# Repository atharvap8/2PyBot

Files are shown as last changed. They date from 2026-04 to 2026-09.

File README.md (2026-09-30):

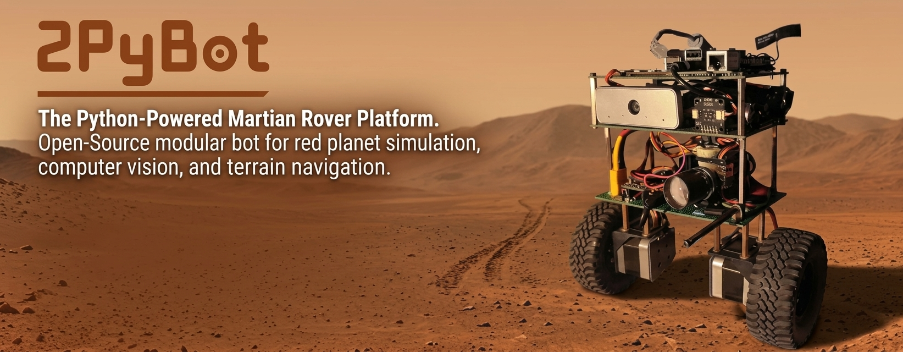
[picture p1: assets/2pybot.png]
2PyBot: The Python-Powered Martian Rover Platform


# 2PyBot: Self-Balancing Robot








2PyBot is an ESP32 self-balancing robot with NEMA 17 steppers, TMC2226 drivers, MT6816 wheel encoders, and an ISM6HG256X IMU. The firmware uses **LQR/LQI state feedback** for balance and position hold. An EVOFOX One S gamepad pairs directly through Bluepad32. USB serial carries host drive commands, telemetry, and parameter tuning.

## Current firmware

- 200 Hz control loop using pitch, pitch rate, wheel position, velocity, and position integral.
- 20 kHz timer ISR for STEP/DIR pulses; hardware PCNT for encoder counts.
- Encoder-differential heading hold and slew-limited steering.
- Normal hold, stiff hold, velocity tracking, and climb reference tracking.
- Terrain roughness, airborne, and landing detection with pitch-gain softening.
- 106 runtime parameters with per-value bounds and NVS save/load.
- Auto-tuning routines for wobble, trim, radius, and stall speed, with current limitations documented in the tuning guide.
- WS2812 status ring, camera pan/zoom servos, and PWM torch.

## Control and communication

The gamepad's left stick drives and steers. The right stick pans and zooms the camera. START requests arming; SELECT stops balancing. LB toggles LOW/HIGH speed, RB toggles the torch, and the D-pad controls hold modes and torch brightness.

Fresh host `V,<forward>,<steering>,<enable>` commands take priority over gamepad driving. `V` commands do not arm the robot. Use gamepad START or serial `E`. With no fresh input, drive commands become zero and balancing continues.

USB serial runs at **460800 baud**. The firmware emits `O` odometry at 50 Hz and `D` debug telemetry at a nominal 100 Hz. Debug starts enabled; `L` toggles it. See the [serial protocol](firmware/BaseLink/PROTOCOL.md) for fields and commands.

## Repository layout

```text
firmware/
  BaseLink/                 Robot firmware and serial protocol
    BaseLink.ino            State machine, control, input arbitration
    config.h                Pins and compiled defaults
    params.h / params.cpp   Runtime parameters and NVS persistence
    autotune.h              Calibration and tuning routines
    terrain.h               Roughness, airborne, and landing detection
    bt_gamepad.h            Bluepad32 input mapping
    imu_sensor.h / .cpp      Mahony attitude estimation
    stepper_control.h / .cpp TMC2226 configuration, PCNT, step ISR
    led_ring.h / .cpp        WS2812 status display
    payload.h               Camera servos and torch
  Controller/               Legacy ESP-NOW joystick transmitter
software/
  android/                  Kotlin/Compose Android app
  radxa/
    console/                Current browser console and Android API
    deployment/             Installed services, MediaMTX, and device rules
  runtime/vision_controller/ Older collision guard and person follower
gui/                        Legacy PID desktop interface
tools/
  controller_lab/           Browser simulation lab
  tuner/                    Legacy Web Serial PID tuner
docs/                       Architecture, control theory, tuning, history
scripts/                    Model generation and Radxa utilities
hardware/cad/enclosure/rev5/ OpenSCAD enclosure source and STL exports
models/                     CAD assets
assets/                     Project media
```

## Build and first connection

1. Install the ESP32 + Bluepad32 board package and the libraries listed in the [firmware setup guide](firmware/BaseLink/README.md).
2. Select ESP32 Dev Module with the Huge APP partition scheme.
3. Open `firmware/BaseLink/BaseLink.ino`, review the pin assignments in `config.h`, and flash.
4. Open USB serial at 460800 baud with newline termination. Check the IMU and driver boot messages, then send `P?` to inspect loaded parameters.
5. Pair the EVOFOX One S in Home+B mode. Leave both sticks centered while calibration completes.
6. Verify motor and sensor signs using the [configuration guide](docs/BaseLink/Config_and_Tuning_Guide.md), then request arming while upright.

Saved NVS parameters take precedence over compiled defaults. `PD` restores defaults in RAM; `PS` saves them.

## Host software status

| Component | Current compatibility |
| :--- | :--- |
| USB terminal or custom serial client | Supports the current parameter and telemetry protocol |
| `software/radxa/console/` | Current Radxa console: 460800 baud, live parameter metadata, browser UI, Android API, and WebRTC camera |
| `software/android/` | Kotlin/Compose client for console HTTP/WebSocket and MediaMTX WHEP; parameter groups are dynamic |
| `software/runtime/vision_controller/radxa_brain.py` | Uses `O` and `V` messages, but still has 115200 baud and 0.035 m radius constants; align both before use |
| `gui/robot_controller_ui.py` | Legacy PID UI: 115200 baud, tab-separated telemetry, and `$` commands; needs a protocol update |
| `tools/tuner/tuner.html` | Legacy Web Serial PID tuner; not a current parameter-store client |
| `firmware/Controller/Controller.ino` | Legacy ESP-NOW transmitter; current BaseLink has no ESP-NOW receiver |

The current console package was imported from the Cubie A7A. See its [setup and API guide](software/radxa/console/README.md) and [deployment layout](software/radxa/README.md). Its debug parser reads the original 15 fields; terrain telemetry and a terrain parameter tab remain pending.

The older Radxa brain provides GUARD/FOLLOW modes. It owns the camera and serial port, so it cannot run alongside the console. See its [setup guide](software/runtime/vision_controller/README_RADXA.md).

The [Android app](software/android/README.md) has Live, Map, Tune, Auto, Camera, and Setup screens. It defaults to the Radxa hotspot address `10.42.0.1`. Its Tune screen includes all groups reported by firmware, including TERRAIN. APK build instructions and CI artifacts are documented with the app.

## Updating the bot

The console runs from `/home/radxa/projects/2PyBot`. After `git pull --ff-only`, a systemd timer applies relevant committed changes and restarts the affected services. Android, CAD, firmware, and documentation changes do not restart the console. See [repo-based deployment](scripts/radxa/README.md) for installation, status, and retry commands.

## Hardware defaults

| Component | Configuration |
| :--- | :--- |
| Robot controller | ESP32 DevKit |
| Wheel drive | Two NEMA 17 motors, TMC2226 drivers, 1/8 microsteps |
| Wheel feedback | MT6816 quadrature encoders, 4096 counts/revolution |
| Wheel radius | 0.050 m compiled default |
| Attitude | ISM6HG256X accelerometer/gyro, Mahony filter |
| Compass | QMC5883L, tilt-compensated yaw telemetry |
| Gamepad | EVOFOX One S through Bluepad32 |
| Status ring | 16 WS2812 LEDs on GPIO 15 |
| Camera payload | MG90S pan/zoom servos on GPIO 26/0; torch on GPIO 2 |

## Enclosure CAD

[Revision 5](hardware/cad/enclosure/rev5/README.md) includes the base tray, shell, face plate, and left/right motor covers as OpenSCAD source and five STL exports. The enclosure is **not yet printed or physically fit-tested**. Estimated dimensions are marked in the source. The imported face STL has three zero-area triangles that need re-export or repair before printing.

The existing simplified STEP model remains in `models/2pybot_simplified.step`; it is separate from the revision-5 enclosure package.

## Documentation

| Document | Contents |
| :--- | :--- |
| [Firmware setup](firmware/BaseLink/README.md) | Build, wiring, pairing, controls |
| [Serial protocol](firmware/BaseLink/PROTOCOL.md) | Commands, parameter records, telemetry fields |
| [Radxa console](software/radxa/console/README.md) | Browser UI, Android API, camera pipeline, deployment |
| [Android app](software/android/README.md) | Build, host connection, screens, parameter and video transport |
| [Radxa deployment](scripts/radxa/README.md) | Git updates, selective restarts, systemd timer, health checks |
| [Enclosure CAD](hardware/cad/enclosure/rev5/README.md) | Revision-5 source, exports, dimensions, and current print status |
| [System architecture](docs/BaseLink/System_Architecture.md) | Sensors, control, actuation, host links |
| [LQR/LQI theory](docs/BaseLink/PID_Theory_and_Math.md) | State feedback, control modes, filtering, limits |
| [Configuration and tuning](docs/BaseLink/Config_and_Tuning_Guide.md) | Defaults, runtime settings, calibration |
| [Program flow](docs/BaseLink/Program_Flow_State_Machine.md) | Boot sequence and state transitions |
| [Troubleshooting](docs/BaseLink/Troubleshooting_Guide.md) | Common faults and source-level checks |
| [Detailed reference](docs/BaseLink/100+_WHAT_AND_HOWS.md) | 126 code-mapped checks |
| [TMC2226 migration](docs/BaseLink/TMC2226_Migration.md) | Driver configuration and migration history |
| [Project history](docs/BaseLink/Project_History.md) | PID, ESP-NOW, LQR/LQI, and runtime-tuning milestones |
| [Legacy transmitter](docs/Controller/System_Architecture.md) | ESP-NOW joystick packet and sampling |

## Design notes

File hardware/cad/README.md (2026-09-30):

# Robot CAD

## Packages

| Path | Contents | Status |
| :--- | :--- | :--- |
| [enclosure/rev5/](enclosure/rev5/README.md) | Parametric OpenSCAD enclosure and five STL exports | Designed; not printed or physically fit-tested |
| [Existing STEP model](../../models/2pybot_simplified.step) | Simplified robot model | Separate reference model |

Revision 5 keeps its SCAD sources, logo SVG, and STL exports together to preserve relative references. Shared dimensions are in `dims.scad`, with part-specific dimensions in the individual sources.

The face STL has three zero-area triangles. Other imported STL edge checks passed. Assembly clearances and printer tolerances still need validation on the physical parts.

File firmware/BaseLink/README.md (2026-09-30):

# BaseLink Firmware

ESP32 robot firmware with LQR/LQI balancing, direct Bluepad32 gamepad input, runtime parameters, terrain adaptation, a WS2812 ring, and camera payload control.

## Build

Open `BaseLink.ino` from this folder. The sketch filename must match the `BaseLink` directory name.

Add both board-manager URLs in Arduino IDE preferences:

```text
https://raw.githubusercontent.com/espressif/arduino-esp32/gh-pages/package_esp32_index.json
https://raw.githubusercontent.com/ricardoquesada/esp32-arduino-lib-builder/master/bluepad32_files/package_esp32_bluepad32_index.json
```

Install **ESP32 + Bluepad32 Arduino**, select **ESP32 Dev Module**, and choose **Huge APP (3 MB)**. Firmware CI uses `esp32-bluepad32:esp32@4.1.0` with this FQBN:

```text
esp32-bluepad32:esp32:esp32:PartitionScheme=huge_app
```

Install these libraries:

- TMCStepper
- STM32duino ISM6HG256X
- QMC5883LCompass
- NeoPixelBus by Makuna

`Preferences` comes with the ESP32 core. The stock ESP32 board package does not supply `Bluepad32.h`. The separate legacy Controller sketch uses the stock ESP32 3.x core.

## Pin map

Values below come from `config.h`.

| Signal | GPIO |
| :--- | :--- |
| Right STEP / DIR | 33 / 25 |
| Left STEP / DIR | 27 / 14 |
| Shared motor EN | 32, active LOW |
| Right UART RX / TX | 16 / 17 |
| Left UART RX / TX | 18 / 19 |
| I2C SDA / SCL | 21 / 22 |
| Left encoder A / B | 4 / 5 |
| Right encoder A / B | 13 / 23 |
| Optional left / right DIAG | 34 / 35 |
| WS2812 DIN | 15 |
| Camera pan / zoom | 26 / 0 |
| Torch MOSFET gate | 2 |

Each driver has a separate UART with a 1 kOhm series resistor on TX. Both drivers use address 0 with MS1/MS2 LOW. Both enable inputs share GPIO 32.

Power the ring and servos from the 5 V rail with common ground. The ring has 16 LEDs, a compiled brightness setting of 200/255, and a 50 Hz refresh setting. GPIO 0 and GPIO 2 are boot-strapping pins; external wiring must preserve their required reset levels.

## Boot and serial connection

Use USB serial at **460800 baud**, 8N1, with newline termination.

Boot loads NVS parameters, plays the ring animation, initializes sensors and drivers, waits 3000 ms, averages 500 gyro readings, then starts the gamepad and payload. The balance state starts at `STATE_IDLE`.

Check for:

```text
[PARAM] 106 tunables ...
[IMU] Initialisation OK
[STEP] RIGHT TMC2226: OK ... readback 1/8 ...
[STEP] LEFT TMC2226: OK ... readback 1/8 ...
[PAD] Bluepad32 ready ...
```

Driver communication errors print per-driver `COMM ERROR` messages. They do not halt setup. IMU initialization failure does halt setup.

Send `P?` to inspect the live settings. `PL` reloads NVS and applies driver tuning after initialization. `PD` restores defaults in RAM; `PS` persists the current settings.

## Gamepad pairing

Put the EVOFOX One S in **Home+B** pairing mode. Keep both sticks centered until the center-calibration log appears. Firmware adopts held buttons on the first processed connection frame; release START before pressing it to arm.

If pairing keys need clearing, enable the existing `BP32.forgetBluetoothKeys()` call for one flash, pair again, then disable that call.

## Controls

| Input | Action |
| :--- | :--- |
| Left stick Y | Forward/backward drive |
| Left stick X | Steering |
| Right stick X | Camera pan rate |
| Right stick Y | Camera zoom rate |
| START | Request arming |
| SELECT | Stop balancing |
| LB | Toggle LOW/HIGH speed |
| RB | Toggle torch |
| D-pad UP | Toggle stiff hold |
| D-pad DOWN | Toggle climb mode |
| D-pad LEFT / RIGHT | Dim / brighten torch; repeat while held |
| Y / B / X / A | Nod yes / nod no / spin / dance |

LOW mode defaults to half drive and steering authority. Boot defaults to LOW. Speed mode remains selected across arm/disarm and reconnection.

`PAD_STEER_ON_LEFT_STICK=0` moves steering to right-stick X and disables camera pan input. This is a compile-time mapping choice.

## Balance and host control

Use START or serial `E` while the robot is within the arm-angle limit, default 5 degrees. `X` or SELECT stops balancing. Tilt beyond 55 degrees or pitch rate beyond 450 degrees/s also stops balancing.

Fresh host `V` lines override gamepad drive for 600 ms by default. Host enable going from 1 to 0 requests a stop; going to 1 does not arm. A first `V,...,0` is not an unconditional stop, so use `X` for an explicit balancing stop.

Gamepad disconnect zeros its axes without disabling balance. When all drive sources are stale, the controller receives zero drive input.

## Ring states

Priority order in `leds_update()`:

1. Fall, arm, or speed-change overlay.
2. Gesture rainbow.
3. Red hazard when host input is fresh, the robot is balancing, drive input is near zero, and measured speed exceeds 0.10 m/s.
4. Violet climb display.
5. Pink position-error display above 0.045 m while holding.
6. Direction beam while driving; amber for reverse.
7. Amber stiff-hold display.
8. Cyan balancing display with tilt-dependent color.
9. Green pending-arm display.
10. Idle ember display.

The hazard display is conditional, not a general indicator that the host owns drive authority. A green gamepad greeting is blended into selected patterns.

## Payload

Pan and zoom use LEDC channels 4/5 at 50 Hz and 16-bit resolution. Torch uses channel 6 at 20 kHz and 10-bit resolution. Camera input is rate-controlled, so releasing the stick leaves the requested position unchanged.

Pan defaults to 120 through 190 degrees with home 165; zoom defaults to 80 through 140 with home 120. The pulse-writing function clamps physical output to 180 degrees even when the requested pan value is higher.

Torch starts off with a compiled preset of 25%. `_torchApply()` clamps duty to the 90% compile-time cap. Payload updates run in both balance states. No disarm-time torch-off call is present in the current sketch.

## Related documentation

- [Serial protocol](PROTOCOL.md)
- [Module map](system_architecture.md)
- [Control theory](../../docs/BaseLink/PID_Theory_and_Math.md)
- [Configuration and tuning](../../docs/BaseLink/Config_and_Tuning_Guide.md)
- [Troubleshooting](../../docs/BaseLink/Troubleshooting_Guide.md)

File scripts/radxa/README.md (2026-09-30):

# Repo-Based Radxa Deployment

The bot runs the console from a Git checkout at `/home/radxa/projects/2PyBot`. A systemd timer checks the local commit about every ten seconds. It does not fetch or pull from GitHub.

## Update

```bash
cd /home/radxa/projects/2PyBot
git pull --ff-only
```

The deployment service waits for Git to finish and rejects tracked local edits. Build/dependency checks happen before service changes. A second Git update during preparation defers deployment to the next check.

## What causes a restart

| Change | Action |
| :--- | :--- |
| Console Python or browser JS/HTML/CSS | Check Python imports, restart console |
| `requirements.txt` | Update the dedicated environment, check imports, restart console |
| Native C/header/Makefile | Build the encoder, restart console |
| Console service template or camera override | Install changed file, reload systemd, restart console |
| MediaMTX source configuration or service | Install changed file, restart MediaMTX and console |
| Encoder device rules | Install/reload rules, restart console |
| Deployment timer/service templates | Update the monitor units |
| Firmware, Android, CAD, documentation | Record the commit without restarting handlers |

The live configuration is `software/radxa/console/mediamtx.yml`. Files under `software/radxa/deployment/` are captured deployment references, not active update inputs.

Firmware still needs a separate compile/flash step. An Android source update needs a separate APK build/install.

## Initial installation

The board needs Git, Python 3.9 or newer with venv/pip, make, the existing console dependencies, MediaMTX, and the Cedar SDK/development libraries described in [the native guide](../../software/radxa/console/native/README.md).

```bash
cd /home/radxa/projects/2PyBot
sudo python3 scripts/radxa/deploy.py --user radxa --force --install-monitor
```

This uses the console service templates with the checkout path and a dedicated Python environment. It does not run the hotspot installer or change NetworkManager configuration.

## Runtime paths

| Path | Contents |
| :--- | :--- |
| `/var/lib/2pybot/` | Existing user camera profiles |
| `/var/lib/2pybot-deploy/venv/` | Dedicated Python environment using available system/user packages |
| `/var/lib/2pybot-deploy/state.json` | Last successfully applied commit and actions |
| `/var/lib/2pybot-deploy/backups/` | Previous installed configuration files, grouped by target commit |
| `/run/2pybot-deploy.lock` | Lock preventing overlapping deployments |
| `/etc/2pybot/mediamtx.yml` | Installed streaming configuration |

State is updated only after commands and service health checks succeed. If video was running before a relevant update, its recovery is also checked. ESP32 serial connection is not required for deployment health.

The monitor runs installation commands as root but reads Git as the checkout owner. This supports the board's Git 2.30 without global ownership exceptions. The console service disables bytecode writes in the source checkout.

## Inspect or retry

```bash
systemctl status 2pybot-deploy.timer
journalctl -u 2pybot-deploy.service -n 50
cat /var/lib/2pybot-deploy/state.json
sudo systemctl start 2pybot-deploy.service
```

Preview pending actions without applying them:

```bash
python3 scripts/radxa/deploy.py --dry-run
```

If a deployment fails, the previous marker stays in place and the timer retries. The script does not reset the checkout or automatically roll back application code. Configuration backups are retained for manual recovery.

`pair2.sh` is the older Linux gamepad-pairing helper. Current BaseLink pairs its gamepad directly to the ESP32.

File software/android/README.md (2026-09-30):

# 2PyBot Android App

Native Kotlin and Jetpack Compose client for the [Radxa console](../radxa/console/README.md). The app uses HTTP for commands and settings, WebSocket for telemetry, and WebRTC/WHEP for camera video.

## Build configuration

| Setting | Value |
| :--- | :--- |
| Application ID / namespace | `in.twopybot.app` |
| Minimum Android version | API 26, Android 8.0 |
| Compile / target SDK | API 34 |
| Java target | 17 |
| Gradle wrapper | 8.9 |
| Android Gradle plugin | 8.5.2 |
| Kotlin | 1.9.24 |
| Compose compiler | 1.5.14 |
| Default robot host | `10.42.0.1` |

Open this directory in Android Studio with JDK 17 and Android SDK 34 installed. The Gradle wrapper scripts, properties, and JAR are included.

The imported Windows wrapper's two missing-Java branches were corrected to return immediately instead of falling through into Gradle startup.

From Windows:

```powershell
.\gradlew.bat :app:assembleDebug
```

From Linux or macOS:

```bash
bash gradlew :app:assembleDebug
```

Debug APK: `app/build/outputs/apk/debug/app-debug.apk`.

`assembleRelease` produces an unsigned release APK. No signing key is included. Machine-specific SDK paths belong in ignored `local.properties`, or use `ANDROID_HOME`.

## Build helper and CI

`build.sh` supports debug, run, release, clean, setup, and doctor modes. Its setup commands use Arch Linux `pacman`; they are not a generic Linux installer.

```bash
bash build.sh doctor
bash build.sh
bash build.sh run
```

The repository's [Android workflow](../../.github/workflows/android.yml) builds debug and unsigned release APKs when Android files change on `main` or `system/**`, on matching pull requests, or through manual dispatch. Artifacts are `2pybot-apk` and `2pybot-apk-release-unsigned`.

## Connection

Join the Radxa hotspot or use its LAN address. Enter the host address in Setup. The app connects to:

| Interface | Address |
| :--- | :--- |
| HTTP API | `http://<host>:8080` |
| Telemetry WebSocket | `ws://<host>:8080/ws` |
| Video | `http://<host>:8889` plus the WHEP path reported by the console |

Default WHEP path is `/cam/whep`. The current Android network configuration permits cleartext traffic through its base configuration; it is not restricted to private IP ranges.

The app communicates with the Radxa, not directly with the ESP32. The console owns USB serial and relays firmware records and parameter writes.

## Screens

| Screen | Contents |
| :--- | :--- |
| Live | WHEP camera, attitude gauge, controller debug values, gesture controls |
| Map | Console dead-reckoned trail and pose; local pose reset |
| Tune | Parameter groups, values, bounds, descriptions, Save/Reload/Defaults |
| Auto | Wobble, trim, radius, and stall commands with progress logs |
| Camera | V4L2 settings, named profiles, exposure/gain adjustment, stream settings |
| Setup | Robot address, stream status, stop control, console logs |

Portrait uses a bottom navigation bar and top stop button. Landscape uses a navigation rail with stop control and wider two-pane screens. See [landscape and auto-tuning](LANDSCAPE_AND_AUTOTUNE.md).

## Parameters and commands

Tune builds its group list from the console parameter payload. Current firmware has **106 parameters in ten groups**, including TERRAIN. Unlike the browser's fixed tab list, the Android group list includes new groups automatically.

Parameter writes change firmware RAM. Save sends the NVS save action; Reload loads saved values; Defaults restores compiled settings without saving.

The console whitelist excludes `E` and `V`, so this app has no direct joystick-driving or balance-arm command. It can send gestures, hold-mode commands, and auto-tune routines. The displayed pad values come from controller debug after input arbitration, and the connection indicator is not a Bluetooth-gamepad pairing status.

The stop button calls `/api/estop`, which sends firmware `X`. That command stops balancing but does not abort the current firmware's stall-search routine. Use Auto's Abort action for `AT,stop`. Radius Done currently encounters the firmware busy-guard bug.

## Source map

| File | Responsibility |
| :--- | :--- |
| `MainActivity.kt` | Six destinations, portrait/landscape navigation, stop control |
| `data/BotRepository.kt` | HTTP/WebSocket models, parameter requests, progress logs, WHEP URL |
| `vm/BotViewModel.kt` | Saved host setting and UI command actions |
| `net/WhepClient.kt` | Receive-only video track, SDP exchange, decoder factory |
| `ui/screens/` | Live, Map, Tune, Auto, Camera, Setup |
| `ui/Responsive.kt` | Orientation helpers |
| `ui/components/Widgets.kt` | Reusable gauges, parameter rows, and status components |

Kotlin files are under `app/src/main/java/in/twopybot/app/`.

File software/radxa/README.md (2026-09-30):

# Radxa Software

The current browser console and Android API are in [console/](console/README.md). The package was imported from `/home/radxa/2pybot-console` on the Cubie A7A.

## Layout

| Path | Contents |
| :--- | :--- |
| `console/console/` | FastAPI server, USB protocol client, camera control, stream supervisor |
| `console/ui/` | Browser interface and parameter tabs |
| `console/native/` | Cedar H.264 publisher source, build file, encoder device rules |
| `console/systemd/` | Installer service templates |
| `deployment/systemd/` | Installed service definitions and camera startup override captured from the board |
| `deployment/udev/` | Installed serial and encoder device rules |
| `deployment/mediamtx.yml` | Live MediaMTX configuration captured from `/etc/2pybot` |
| `deployment/bin/` | Local copy of the installed MediaMTX binary; ignored by Git |
| `deployment/runtime/` | Local copy of saved camera profiles; ignored by Git |

The running board used MediaMTX **v1.9.3**. The console uses **460800 baud**, requests firmware parameter metadata, and serves HTTP/WebSocket on port **8080**. MediaMTX exposes WHEP on **8889**, RTSP on **8554**, and its local administration API on **9997**.

The [Android app](../android/README.md) consumes the console API and MediaMTX WHEP stream. It builds parameter groups dynamically from the firmware metadata.

The bot runs this package from `/home/radxa/projects/2PyBot/software/radxa/console`. A [commit-aware deployment timer](../../scripts/radxa/README.md) applies relevant changes after a manual `git pull --ff-only`.

The existing [vision controller](../runtime/vision_controller/README_RADXA.md) is a separate older host application. It must not open the same camera or serial port while the console is using them.

## Import record

The original source, backup files, executables, and deployed settings were downloaded to a local snapshot before importing. Application source and deployment configuration are kept here. Generated executables, captures, and device-specific runtime profiles are retained locally and excluded from commits.

The separate camera/ToF calibration application is outside this package. The camera controls already built into the console remain included.

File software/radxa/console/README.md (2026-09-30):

# 2PyBot Console

Browser tuning interface, telemetry, camera controls, and HTTP/WebSocket API for the Android app. Imported from the running Cubie A7A package at `/home/radxa/2pybot-console`.

The Kotlin/Compose client is in [software/android](../../android/README.md).

## Components

| Path | Responsibility |
| :--- | :--- |
| `console/server.py` | FastAPI endpoints, WebSocket feed, static browser UI |
| `console/serial_link.py` | Exclusive USB connection, parameter commands, telemetry parsing, dead reckoning |
| `console/config.py` | Serial, HTTP, camera, snapshot, and profile settings |
| `console/camera.py` | V4L2 controls, exposure/gain adjustment, profiles, JPEG snapshots |
| `console/stream.py` | Camera mode selection, encoder startup, progress metrics, process supervision |
| `ui/` | Browser shell, shared parameter renderer, twelve tabs |
| `native/` | Allwinner Cedar H.264 publisher and probe source |
| `systemd/` | Installer templates for console and MediaMTX |

## Firmware connection

Serial defaults to `/dev/ttyUSB0` at **460800 baud** with DTR/RTS disabled and exclusive ownership. The reader requests `P?` after connecting and retries when the port is unavailable.

- `P` rows populate the parameter editor, including bounds, group, and description.
- `PR` rows provide live geometry conversions; odometry uses `COUNTSM` when available, otherwise a 0.050 m radius fallback.
- `P!` acknowledges a write and requests a new dump.
- `PS`, `PL`, and `PD` provide firmware persistence actions.
- `O` records update pose and telemetry.
- `D` records populate the original 15 debug fields. The five newer terrain fields are currently ignored.

The browser has parameter tabs for BALANCE, STEPPER, DRIVE, YAW, SAFETY, IMU, CLIMB, LED, and PAYLOAD. Firmware TERRAIN parameters are available through the API, but a terrain tab is not registered yet. Map dead reckoning uses the fixed 0.155 m track width from `config.py`.

The API command whitelist excludes `E` and `V`. The gamepad remains connected to the ESP32. `AT,` commands are allowed, so the firmware's current stall-tuning limitations still apply.

## Addresses

| Interface | Address |
| :--- | :--- |
| Browser console and API | `http://<radxa-ip>:8080` |
| WebSocket telemetry | `ws://<radxa-ip>:8080/ws` |
| WebRTC WHEP | `http://<radxa-ip>:8889/cam/whep` |
| Local camera publication | `rtsp://127.0.0.1:8554/cam` |
| MediaMTX administration | `http://127.0.0.1:9997` |

The installed hotspot normally uses `10.42.0.1`. Use your configured hotspot password; no device credentials are stored in this package.

## Install on the Radxa

The current bot uses the repository checkout at `/home/radxa/projects/2PyBot`, with this application under `software/radxa/console`. Use [repo-based deployment](../../../scripts/radxa/README.md) for normal updates and service monitoring.

The standalone installer below is for dependency/hotspot setup on a new board. It is not needed for routine Git updates. Its service templates substitute the application's installation directory.

The installer needs root access and a hotspot password in `PSK`:

```bash
cd /home/radxa/2pybot-console
read -rs -p 'Hotspot password: ' PSK
export PSK
sudo -E bash install.sh
```

It installs Python/stream dependencies, creates `/var/lib/2pybot`, sets dialout/video membership, installs the serial udev rule, configures a NetworkManager hotspot, and installs the two services. MediaMTX is downloaded if not already installed; the captured board version was **v1.9.3**.

The native Cedar publisher is built separately. See [native/README.md](native/README.md) for SDK and development-package requirements. The source `install.sh` does not build that executable or install its encoder rules.

The running board also has a camera startup override. Install the captured override and encoder rule when restoring that setup:

```bash
sudo mkdir -p /etc/systemd/system/2pybot-console.service.d
sudo cp 20-camera-natural.conf /etc/systemd/system/2pybot-console.service.d/
sudo cp native/99-2pybot-encoder.rules /etc/udev/rules.d/
sudo udevadm control --reload-rules
sudo systemctl daemon-reload
sudo systemctl restart 2pybot-console
```

The deployed service definitions and live MediaMTX settings are also preserved in [deployment/](../deployment/). Those service definitions contain the original `/home/radxa/2pybot-console` path; the installer templates substitute the actual destination.

## Camera pipeline

For MJPEG modes, the console selects `native/2pybot_hwstream` when present. It decodes JPEG on the CPU, converts pixels, encodes H.264 with Cedar, publishes RTSP, and writes original JPEG snapshots to `/dev/shm/2pybot_snap.jpg`.

Without that executable, it probes FFmpeg hardware encoders and falls back to low-latency libx264. The supervisor restarts failed stream processes. `/api/stream` reports the selected mode, encoder, errors, and progress metrics.

Camera profiles are daylight, indoor, low_light, night, and driving. Built-in exposure adjustments cap absolute exposure at 300 units. User profiles live in `/var/lib/2pybot/camera_profiles.json`; the board's saved copy was downloaded as local runtime data.

## API

| Method and path | Purpose |
| :--- | :--- |
| `GET /api/status` | Connection, telemetry, debug, derived values, stream state, parameter count |
| `GET /api/params` | Parameters, groups, bounds, and dump status |
| `POST /api/params/set` | Send `{key, value}` |
| `POST /api/params/{save,load,defaults,refresh}` | Firmware parameter actions |
| `POST /api/command` | Send a whitelisted `{line}` |
| `POST /api/estop` | Send firmware `X` |
| `GET /api/path`, `POST /api/pose/reset` | Pose trail and local pose reset |
| `GET /api/log` | Recent console logs |
| `GET /api/camera/controls` | V4L2 controls, values, profiles, and camera modes |
| `POST /api/camera/set` | Set `{name, value}` |
| `POST /api/camera/profile/{name}` | Apply a camera profile |
| `POST /api/camera/autocalibrate` | Adjust exposure/gain from snapshot brightness |
| `GET /api/camera/snapshot`, `GET /api/camera/luma` | JPEG and brightness measurement |
| `GET /api/stream` | Stream state and metrics |
| `POST /api/stream/restart`, `POST /api/stream/stop` | Stream process control |
| `WS /ws` | 10 Hz telemetry, parameter acknowledgements, and logs |

`/api/camera/profile/save` is defined after the generic profile route in the imported code. Route ordering needs review before relying on profile saving through HTTP.

## Operation

```bash
systemctl status 2pybot-console 2pybot-mediamtx
journalctl -u 2pybot-console -f
journalctl -u 2pybot-mediamtx -f
```

Run only one application against the ESP32 serial port and camera. The older `radxa_brain.py` owns both and should not run alongside this console.

The separate camera/ToF calibration service was not imported. Camera controls contained in this console are part of the downloaded application.

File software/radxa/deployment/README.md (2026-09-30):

# Captured Cubie Deployment

Configuration downloaded from the running `2pybot` board with the console source. The original application path is `/home/radxa/2pybot-console` and the service user is `radxa`.

| Repository file | Original board path |
| :--- | :--- |
| `systemd/2pybot-console.service` | `/etc/systemd/system/2pybot-console.service` |
| `systemd/2pybot-console.service.d/20-camera-natural.conf` | `/etc/systemd/system/2pybot-console.service.d/20-camera-natural.conf` |
| `systemd/2pybot-mediamtx.service` | `/etc/systemd/system/2pybot-mediamtx.service` |
| `mediamtx.yml` | `/etc/2pybot/mediamtx.yml` |
| `udev/99-2pybot.rules` | `/etc/udev/rules.d/99-2pybot.rules` |
| `udev/99-2pybot-encoder.rules` | `/etc/udev/rules.d/99-2pybot-encoder.rules` |

These are the installed files, separate from the installer's templates. The camera drop-in is part of the deployed setup and applies natural-color controls before the console starts.

These captures describe the pre-Git standalone deployment. The current console service is rendered from its template for `/home/radxa/projects/2PyBot/software/radxa/console` by [the deployment script](../../../scripts/radxa/README.md). Edits to this captured directory do not trigger handler restarts.

MediaMTX was **v1.9.3**, running from `/usr/local/bin/mediamtx`. Its downloaded executable is retained locally at `bin/mediamtx`, which is ignored by Git. Saved camera profiles from `/var/lib/2pybot` are retained locally under `runtime/`, also ignored.

The live MediaMTX settings enable TCP RTSP on 8554, WebRTC on 8889 with UDP media on 8189, and the administration API on localhost 9997. The `cam` path accepts a publisher. HLS, RTMP, and SRT are disabled.

Use [the console setup guide](../console/README.md) when installing or restoring the application. Review the absolute paths before applying these captured service definitions to another board.

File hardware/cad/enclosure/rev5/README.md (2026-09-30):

# Enclosure Revision 5

OpenSCAD source and STL exports imported from `2pybot-covers-rev5`.

**Status: designed, not yet printed or physically fit-tested.** Dimensions marked `ROUGH` still need measurement against the assembled robot. Mesh checks do not establish physical clearance or printability.

## Files

| Source | Export | Part |
| :--- | :--- | :--- |
| `base.scad` | `base.stl` | Bottom board tray and shell attachment pads |
| `shell.scad` | `shell.stl` | Main cover, lid, ring channel, and cable/camera openings |
| `face.scad` | `face.stl` | Camera/ToF face plate and logo |
| `motor.scad` with `side="L"` | `motor_L.stl` | Left motor/standoff cover |
| `motor.scad` with `side="R"` | `motor_R.stl` | Right motor/standoff cover |
| `dims.scad` | None | Shared dimensions, fit allowances, fasteners, and coordinate frame |
| `logo.scad`, `logo_B.svg` | Included in face export | Extruded face logo |

Keep the source and SVG files together. `face.scad` uses `logo.scad`, which imports `logo_B.svg` by relative path.

## Coordinate frame

Origin is the bottom-deck front-left corner, with z=0 at the solder-side face. X runs left to right when viewed from the front, Y front to back, and Z upward. Exports use assembly coordinates; orient and place each part on the build plate in the slicer.

## Current dimensions

| Feature | Source value |
| :--- | :--- |
| Board width/depth/thickness | 150 / 90 / 1.6 mm |
| Bottom-to-mid clear gap | 60 mm |
| Mid-to-top clear gap | 40 mm |
| Sliding fit allowance | 0.3 mm per side |
| M3 pilot / clearance diameter | 2.5 / 3.4 mm |
| Corner hole inset / diameter | 3.5 / 3.2 mm, estimated |
| Motor standoff square | 30 mm, estimated |
| Tray motor openings | Two 44 mm squares |
| Lens opening | 26 x 18 mm, estimated |
| Ring outer/inner diameter | 68 / 54 mm |
| Ring channel depth | 4.5 mm |

Shared dimensions live in `dims.scad`. Ring, camera, fan, and face-opening dimensions also have local definitions in `shell.scad` and `face.scad`.

## Export

Run from this directory with OpenSCAD installed:

```bash
openscad -o base.stl base.scad
openscad -o shell.stl shell.scad
openscad -o face.stl face.scad
openscad -D 'side="L"' -o motor_L.stl motor.scad
openscad -D 'side="R"' -o motor_R.stl motor.scad
```

Text uses `DejaVu Sans:style=Bold`; install that font when reproducing the exports.

## Intended assembly

The tray supports the board on ledges and corner posts. The shell slides over the tray and attaches through side pads and top rear screws. Motor covers slide outboard 3 mm below their final position, then lift into the tray openings and attach through two tabs each.

The supplied design note calls for fitting the left cover before mounting the right motor, or tilting it into place. Verify that sequence on the printed parts. Motor, connector, encoder, standoff, and cable envelopes include estimated dimensions.

Material, print orientation, supports, and manufacturing tolerances have not been validated on a physical print.

## Imported mesh checks

All five exports have closed edges, consistent edge orientation, and positive signed volume. `face.stl` contains **three zero-area triangles**; the other four exports contain none. Re-export or repair the face mesh before printing. No part-intersection or physical-clearance check was performed during import.

| Export | Triangles | Bounding-box size, mm | Zero-area triangles |
| :--- | :--- | :--- | :--- |
| `base.stl` | 5036 | 156.6 x 96.6 x 16.6 | 0 |
| `shell.stl` | 9474 | 162.8 x 102.8 x 140.6 | 0 |
| `face.stl` | 3904 | 150.0 x 13.29 x 44.0 | 3 |
| `motor_L.stl` | 2140 | 63.5 x 62.8 x 86.4 | 0 |
| `motor_R.stl` | 2496 | 63.5 x 62.8 x 86.4 | 0 |

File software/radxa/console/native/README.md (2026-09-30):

# Cubie A7A hardware camera publisher

`2pybot_hwstream` captures MJPEG from the USB camera and uses Allwinner's
**Cedar VE2 H.264 encoder** directly. JPEG decoding and pixel conversion run
on the CPU; H.264 encoding does not use libx264 or the GPU/NPU.

The console selects this backend for MJPEG modes when the executable exists.
The process publishes `rtsp://127.0.0.1:8554/cam` and atomically writes original
JPEG snapshots to `/dev/shm/2pybot_snap.jpg` for calibration.

## Build

The Radxa image needs `libcedarc-dev-2.0.0-arm64` and the compiler/development
packages `build-essential`, `pkg-config`, `libavcodec-dev`, `libavformat-dev`,
`libavutil-dev`, and `libswscale-dev`.

```sh
make -C /home/radxa/projects/2PyBot/software/radxa/console/native
sudo systemctl restart 2pybot-console.service
```

Install `99-2pybot-encoder.rules` in `/etc/udev/rules.d/` and ensure the console
user belongs to `video`. The rules grant access to the two Cedar devices and
the system DMA heap independently of desktop login ACLs.

## Buffering and timestamps

- Request four V4L2 capture buffers and drain completed buffers to the latest frame.
- Reject frames older than 200 ms, corrupted frames, and non-increasing timestamps.
- Use monotonic kernel capture time for RTP; wall-clock/NTP changes cannot affect it.
- Hardware Baseline encoding has no B-frame reordering and an IDR every half second.
- Publish directly through the RTSP muxer, without an intermediate encoder FIFO.
- Bound a blocked RTSP write to 500 ms; the console supervisor restarts failed publishers.
- A five-second frame-processing watchdog terminates a stuck publisher so the
  supervisor can restart it; start/stop operations are serialized in the console.
- Convert full-range JPEG to limited-range NV12 explicitly and signal the BT.601
  matrix/range in the H.264 stream.

`GET /api/stream` reports `encoder: cedar_h264`, `hardware: true`, and progress
metrics. `capture_to_publish_ms` measures kernel capture timestamp to completion
of the local RTSP write; it does not include the phone's network/decoder/display.
`drop_frames` counts intentionally discarded stale/queued/invalid frames.
`timestamp_fallbacks` counts camera timestamps that could not be used as monotonic
capture times (normally zero). CPU-decoder errors and hardware failures are
available in `journalctl -u 2pybot-console.service`.

The deployment timer rebuilds this executable when tracked native source or Makefile changes are pulled. The compiled binary is ignored by Git.

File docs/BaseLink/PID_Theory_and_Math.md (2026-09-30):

# LQR/LQI Control Theory and Implementation

The current balance controller is implemented in [BaseLink.ino](../../firmware/BaseLink/BaseLink.ino). It uses state feedback with a position integral. Earlier PID control is covered in [project history](Project_History.md).

## State and units

| Symbol | Firmware value | Units |
| :--- | :--- | :--- |
| x | `posM`, encoder-average position | m |
| x_ref | `xRef`, position reference | m |
| v | `velF`, filtered encoder velocity | m/s |
| theta | `pitchF * DEG_TO_RAD` | rad |
| omega | `rateF * DEG_TO_RAD` | rad/s |
| z | `zInt`, integral of position error | m·s |
| u | `uOut`, requested wheel acceleration | m/s² |

Pitch and pitch rate are measured independently. The rate term comes from the gyro, not a numerical derivative of filtered pitch. Wheel position comes from MT6816 feedback, not generated step counts.

## Normal position hold

Let the position error be limited by `P.exClamp`:

$$e_x = \operatorname{clip}(x-x_{ref},-e_{max},e_{max})$$

The integral is accumulated and limited by `P.zIntLim`:

$$z_{next} = \operatorname{clip}(z+e_x\Delta t,-z_{max},z_{max})$$

The controller requests acceleration:

$$u = -(K_1e_x + K_2v + K_3\theta + K_4\omega + K_5z)$$

The K1 to K5 terms respectively act on position, velocity, pitch, pitch rate, and position integral. The integral compensates sustained position error. It is not an integral of pitch error.

Compiled normal gains:

| Gain | Default |
| :--- | :--- |
| K1 | -7.0547 |
| K2 | -6.5334 |
| K3 | -34.5881 |
| K4 | -4.2854 |
| K5 | -2.1082 |

These negative gains are used with the leading minus sign shown above. Their effect depends on the sensor and motor sign conventions. NVS settings can replace the defaults.

## Velocity tracking

When forward input exceeds `DRIVEDB`, normal driving switches to velocity tracking:

$$v_{in} = cmdFwd\,P.maxDriveV$$
$$u = -(K_2(v-v_{in}) + K_3\theta + K_4\omega)$$

`zInt` is zeroed. The hold reference moves to `posM + velF * P.brakeLook`, providing a braking lookahead when input returns to zero. Joystick input requests velocity rather than a target lean angle.

## Stiff hold and climb

Stiff hold uses S1 to S5 with the same five-state expression while not driving. Active drive input selects the normal velocity branch instead.

Climb mode runs before the driving test. It ramps the position reference with `cmdFwd * P.climbVel`, confines the reference within `P.exClamp` of the robot, and uses C1 to C5 with a wider integral bound `P.climbZLim`. Steering authority is multiplied by `P.climbStr`.

Changing mode or gains does not establish a guaranteed slope limit. Traction, motor torque, geometry, supply voltage, and acceleration headroom determine the hardware envelope.

## Acceleration, velocity, and saturation

$$u_{limited}=\operatorname{clip}(u,-a_{max},a_{max})$$
$$v_{cmd,next}=\operatorname{clip}(v_{cmd}+u_{limited}\Delta t,-v_{max},v_{max})$$

Above 90% of the velocity ceiling, the reference moves toward measured position using `VSATBLD`, and the integral decays. This gives up position error rather than keeping an unreachable hold target.

Conversions are recomputed in `params_recompute()`:

$$stepsPerM=\frac{200\times8}{2\pi R}$$
$$countsPerM=\frac{4096}{2\pi R}$$
$$v_{max}=\frac{MAXSPD}{stepsPerM},\qquad a_{max}=\frac{MAXACC}{stepsPerM}$$

For the current 0.050 m radius, 8500 microsteps/s speed limit, and 20000 microsteps/s² acceleration limit, these give approximately 5093 steps/m, 13038 counts/m, 1.67 m/s, and 3.93 m/s². The default drive request limit is 0.70 m/s.

## Terrain gain adaptation

`terrain.h` estimates roughness from acceleration-magnitude error and pitch rate:

$$roughInput=|\|a\|-1|+0.35\frac{|pitchRate|}{400}$$

An EMA with `TERRTAU` smooths the estimate. Roughness progressively reduces the gain multiplier from 1 to `TERRSOFT`, default 0.55. Confirmed airborne and landing states use the full softening value.

- Normal hold and velocity tracking multiply K3/K4 by this value.
- Climb multiplies C3/C4.
- Stiff-hold S3/S4 remain unchanged.
- `AIRFRZ` suppresses integral accumulation in hold and climb while airborne. Saturation bleed remains active; driving still resets the integral.

## Heading control

Heading is represented by right-minus-left encoder counts. With no steering command:

$$steerSteps=\operatorname{clip}(dErr\,P.yawKp-diffRateF\,P.yawKd,-P.yawMaxSt,P.yawMaxSt)$$

The look command adds a heading offset converted through track width and counts per metre. Large differential error or excessive pitch re-latches heading. Compass yaw is telemetry, not the heading-control measurement.

The wheel rates are:

$$left=v_{cmd}\,stepsPerM-steerSteps$$
$$right=v_{cmd}\,stepsPerM+steerSteps$$

The common velocity is constrained by `P.vMax`; the final per-wheel rates are clamped to the 20 kHz timer limit by `setSpeeds()`.

## Filtering

The Mahony estimate uses accelerometer and gyro feedback. Two cascaded pitch EMAs use:

$$\alpha=1-e^{-2\pi f_c/200}$$

`IMUCUT` sets the pitch cutoff, default 50 Hz. Encoder velocity and differential rate use a 15 Hz EMA. Lower cutoffs reduce noise but add delay. There is no PID derivative-filter parameter in the current sketch.

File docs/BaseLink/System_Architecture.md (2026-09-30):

# BaseLink System Architecture

Reference: [BaseLink firmware](../../firmware/BaseLink/). Balancing runs on the ESP32. The Radxa supplies drive commands; it does not close the balance loop.

## Data flow

```text
ISM6HG256X -> Mahony + pitch filter -> pitch and pitch rate
MT6816 encoders -> PCNT -> position, velocity, encoder difference
Accelerometer magnitude -> terrain estimate -> pitch-gain multiplier
Bluepad32 gamepad + USB V commands -> input arbitration
Measurements + commands + runtime parameters -> LQR/LQI controller
Acceleration -> integrated wheel velocity -> steering split
Left/right step rates -> 20 kHz timer ISR -> TMC2226 STEP/DIR
```

The QMC5883L provides tilt-compensated yaw telemetry. Heading control uses wheel encoder difference, not compass yaw.

## Execution rates

| Task | Default rate | Implementation |
| :--- | :--- | :--- |
| Sensor reads, control, input handling | 200 Hz | `BaseLink.ino::loop()` |
| Step generation | 20 kHz | `StepperControl::tick()` |
| Odometry stream | 50 Hz | `ODOM_PERIOD_MS=20` |
| Debug stream | Nominal 100 Hz | `DEBUG_PERIOD_MS=10`; enabled at boot |
| LED refresh | 50 Hz | `P.ledFps` |
| Servo writes | 50 Hz | `P.svRate`; LEDC pulses remain at 50 Hz |

The loop gates on 5000 microseconds, uses measured elapsed time, and caps `dt` at 0.05 s after stalls. These are scheduling targets, not guarantees of constant latency.

## Sensors and estimation

`imu_sensor.cpp` reads accelerometer and gyro data over 400 kHz I2C. It subtracts calibrated gyro bias, integrates a six-axis Mahony quaternion, and applies two cascaded EMA stages to pitch. When acceleration magnitude differs from 1 g by more than 0.2 g, the proportional correction is set to 0.1.

Compass offsets and signs are applied separately before tilt-compensated yaw calculation. Magnetometer measurements are not fed into the Mahony gravity correction.

Two PCNT units decode encoder A/B edges at four times the encoder pulse resolution. Overflow handlers extend the counters to 64 bits. The right count is negated in `getPositionR()` to match the left wheel convention.

`BaseLink.ino` converts average counts to metres and differentiates them for velocity. Velocity and encoder-difference rate use a 15 Hz EMA.

## Balance and steering

`runController()` selects one of these modes:

| Mode | Controller |
| :--- | :--- |
| Normal hold | Five-state LQI with clamped position error and integral |
| Driving | K2/K3/K4 velocity tracking; integral reset to zero |
| Stiff hold | S1 to S5 gain set while not driving |
| Climb | C1 to C5 gain set tracking a moving position reference |

Acceleration is limited to `P.aMax`, integrated into `vCmd`, and limited to `P.vMax`. Near velocity saturation, the hold reference and integral bleed toward the measured state.

Steering adds opposite rate offsets to the wheels. Active steering is slew-limited. With the steering stick centered, proportional and derivative feedback holds encoder difference. Large encoder error or excessive tilt re-latches heading instead of unwinding a possible slip.

## Terrain adaptation

`terrain.h` filters acceleration-magnitude deviation and a pitch-rate term into roughness. Low acceleration magnitude confirms an airborne state; touchdown starts a landing interval.

The gain multiplier applies to K3/K4 in normal hold and driving, and C3/C4 in climb. Stiff-hold S3/S4 are unchanged. With `AIRFRZ` enabled, airborne detection suppresses integral accumulation in hold and climb. Saturation bleed can still change the integral. Driving always resets it.

## Inputs and arming

Drive priority is fresh USB `V` commands, then fresh gamepad input, then zero. Default freshness windows are 600 ms and 200 ms respectively.

- START generates an arm request; SELECT generates a stop event.
- Serial `E` also requests arming; `X` stops balancing.
- A `V` enable transition from 1 to 0 requests a stop. A transition to 1 does not request arming.
- Arming requires `abs(pitchF) < P.armAngle`, default 5 degrees.
- A fall or rate spike disables balancing and returns to `STATE_IDLE`.
- Gamepad disconnect zeros its axes and stops refreshing its timestamp. It does not disarm balancing.

Gamepad sticks use center calibration, radial deadzone/rescaling, an angle-based steering taper, and exponential response. Buttons held on the first processed connection frame are adopted as the baseline.

## Parameters and persistence

`params.h` defines 106 fields and their defaults, bounds, groups, and descriptions. `params.cpp` owns the single `P` instance. Parameter writes recompute geometry conversions and call the hardware-update hook.

`PS` saves to the `2pybot` NVS namespace. `PL` loads saved values. `PD` restores compiled defaults in RAM. Per-value bounds do not validate relationships such as minimum versus maximum servo travel.

The first hardware-update callback is skipped during boot. Loaded motor current and IMU cutoff are used by initialization; StallGuard and CoolStep initialization still uses compiled defaults. `PL` after initialization applies the loaded driver tuning.

## Actuation and payload

TMC2226 drivers use `TMC2209Stepper`, separate 115200 baud UARTs, address 0, and a shared active-low enable on GPIO 32. Boot checks connection status and an IFCNT increment after one verification write. STEP/DIR pulses come from the timer ISR, not UART commands.

NeoPixelBus drives the WS2812 ring through RMT. LEDC drives pan, zoom, and torch on separate PWM channels. Payload updates continue while idle. The torch hard cap is 90% in the current code, and the physical servo pulse mapping clamps angles to 0 through 180 degrees.

## Host interfaces

The active firmware uses USB `Serial` at 460800 baud. The [Radxa console](../../software/radxa/console/README.md) owns that connection and serves browser/Android clients through HTTP and WebSocket. Its camera pipeline publishes H.264 through MediaMTX for WebRTC/WHEP clients.

There is no `SerialBT` command service or ESP-NOW receiver. See [PROTOCOL.md](../../firmware/BaseLink/PROTOCOL.md) for the wire format and [README.md](../../README.md) for host-tool compatibility.

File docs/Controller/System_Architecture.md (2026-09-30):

# Legacy ESP-NOW Joystick Transmitter

Reference: [Controller.ino](../../firmware/Controller/Controller.ino). This sketch remains in the repository for the older ESP-NOW control path. Current BaseLink uses a direct Bluepad32 gamepad and has no ESP-NOW receiver.

## Hardware and build

| Signal | GPIO |
| :--- | :--- |
| Joystick X | 34, ADC1 |
| Joystick Y | 35, ADC1 |
| Joystick switch | 32, pull-up, active LOW |
| Status LED | 2 |

Power the joystick at 3.3 V with common ground. ADC1 is used because Wi-Fi occupies ADC2 resources. The sketch uses the stock ESP32 Arduino 3.x core and the `wifi_tx_info_t` send-callback signature. Serial diagnostics run at 115200 baud.

Set `receiverMAC[]` to the intended legacy receiver's STA address. The transmitter configures an unencrypted peer on channel 0.

## Sampling and processing

1. On boot, average 64 samples per axis at 5 ms spacing to capture the resting center.
2. Every 20 ms, average four ADC readings per axis.
3. Subtract the calibrated center and divide by `JOY_RANGE=2048`.
4. Apply an EMA with `JOY_SMOOTH=0.7`.
5. Apply a 0.10 deadzone and rescale the remaining range.
6. Clamp to -1 through 1, then scale forward by 5.0 and steering by 1.0.
7. Poll the switch. A press edge toggles the enable flag; no explicit debounce interval is implemented.
8. Send the packed packet when the peer was added successfully.

## Packet

```cpp
typedef struct __attribute__((packed)) {
    float forward;
    float steering;
    uint8_t enable;
} JoystickPacket;
```

The packed payload is 9 bytes: two 32-bit floats and one enable byte. Forward uses the legacy -5 through +5 target-offset units; steering is -1 through +1. The receiver must agree on layout, scaling, and radio channel.

## Diagnostics

- Boot prints the local STA MAC, target MAC, center calibration, and peer status.
- ESP-NOW initialization failure halts the sketch.
- Peer-add failure leaves it running without transmission.
- Failed sends toggle the status LED.
- Every 200 ms, serial prints forward, steering, and enable values.

For the active gamepad mapping and pairing instructions, see [BaseLink README](../../firmware/BaseLink/README.md).

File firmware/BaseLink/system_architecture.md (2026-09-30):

# BaseLink Module Map

The full [system architecture](../../docs/BaseLink/System_Architecture.md) describes control flow and timing. This file maps the current sketch modules.

| File | Responsibility |
| :--- | :--- |
| `BaseLink.ino` | Boot, 200 Hz loop, two-state balance machine, LQR/LQI, steering, serial parsing, drive arbitration, telemetry |
| `config.h` | Pin assignments, sensor mapping, PWM/timer settings, compiled parameter defaults |
| `params.h` | Parameter fields, bounds, keys, groups, metadata, declarations |
| `params.cpp` | Shared `P` instance, NVS persistence, parameter commands, derived conversions |
| `autotune.h` | Wobble, trim, radius, and stall-search state machine |
| `terrain.h` | Roughness filter, airborne/landing states, gain multiplier |
| `imu_sensor.h` / `imu_sensor.cpp` | ISM6HG256X reads, gyro calibration, six-axis Mahony, filtered pitch, compass yaw |
| `stepper_control.h` / `stepper_control.cpp` | TMC2226 UART setup, live driver tuning, PCNT encoder reads, 20 kHz STEP/DIR ISR |
| `bt_gamepad.h` | Bluepad32 pairing, stick shaping/calibration, button events, payload input |
| `led_ring.h` / `led_ring.cpp` | RMT-driven WS2812 status patterns |
| `payload.h` | LEDC pan/zoom servo pulses and torch brightness |
| `PROTOCOL.md` | USB command, parameter, and telemetry reference |

## Interfaces

- `IMUSensor` supplies pitch, gyro pitch rate, acceleration, and yaw.
- `StepperControl` supplies encoder counts and accepts signed left/right step rates.
- `P` supplies the live settings used by control and peripheral code.
- `btgamepad_takeEnableEvent()` supplies START/SELECT events independently of drive priority.
- `terrain_soften()` supplies the pitch-gain multiplier; `terrain_airborne()` gates integral accumulation.
- USB `V` messages supply normalized forward and steering requests. They do not arm the robot.
- [The Radxa console](../../software/radxa/console/README.md) reads parameter/telemetry records and exposes tuning, camera, and stream APIs to browser and Android clients. Its command whitelist does not include `V` or `E`.

There are no active `pid_controller`, `serial_tuner`, `espnow_comm`, or Bluetooth serial modules in this sketch. The legacy desktop GUI and PID browser tuner need protocol changes to support current BaseLink.

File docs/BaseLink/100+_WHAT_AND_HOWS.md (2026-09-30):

# BaseLink Code Reference: 126 Checks

References are relative to [firmware/BaseLink](../../firmware/BaseLink/). Runtime keys come from `params.h`; use `P,key,value` at 460800 baud. See [PROTOCOL.md](../../firmware/BaseLink/PROTOCOL.md) for record fields and commands.

## Balance and state

| # | Question or symptom | Source | Check / behavior |
| :--- | :--- | :--- | :--- |
| 1 | Which controller balances the robot? | `BaseLink.ino::runController()` | LQR/LQI state feedback; no active pitch PID module |
| 2 | E is accepted but motors stay off | `loop()`, `P.armAngle` | Arming waits for corrected pitch below `ARMANG`, default 5 degrees |
| 3 | Robot falls immediately after arming | `pitchF`, `rateF`, motor direction | Verify sensor, encoder, and motor signs before adjusting gains |
| 4 | Normal hold drifts | `k1`, `k5`, `zInt` | Inspect geometry, trim, position error, integral limits, and saturation |
| 5 | Position recovery is too aggressive | `P.exClamp`, K1 | `EXCLAMP` bounds the position error used by hold |
| 6 | Slow integral recovery | K5, `P.zIntLim` | `ZLIM` bounds position integral; it is not a pitch integral |
| 7 | Why does the integral disappear during driving? | Driving branch | Velocity tracking resets `zInt` each loop |
| 8 | Braking parks away from the original point | `P.brakeLook`, `xRef` | Driving updates the hold reference from position and velocity |
| 9 | Stiff hold has no effect while driving | Controller branch order | Normal velocity tracking takes priority over stiff hold |
| 10 | Climb mode changes steering feel | `P.climbStr` | Climb scales steering authority, default 0.40 |
| 11 | Climb reference gets ahead of the robot | `xRef` clamp | Reference remains within `EXCLAMP` of measured position |
| 12 | Hold mode disappears after arming | `resetController()` | Arming resets stiff/climb flags; select the mode afterward |
| 13 | Speed saturates under a push | `satV`, `P.vMax` | Inspect motor authority, common velocity limit, and geometry |
| 14 | Acceleration saturates | `satA`, `P.aMax` | `MAXACC` determines the derived acceleration cap |
| 15 | Hold reference moves under saturation | Saturation-bleed block | Above 90% of `vMax`, `VSATBLD` moves reference toward position |
| 16 | R does not stop the robot | Serial `R`, `resetController()` | R resets controller state without disabling motors |
| 17 | Fall recovery does not arm automatically | `requestDisable()` | A new START press or E request is required |
| 18 | Where is STATE_FALLEN? | `RobotState` | Only idle and balancing states exist |
| 19 | Excessive tilt stops balancing | `P.maxTilt` | Default `MAXTILT` is 55 degrees |
| 20 | A rate spike stops balancing | `P.maxRate` | Default `MAXRATE` is 450 degrees/s |

## IMU and encoder estimation

| # | Question or symptom | Source | Check / behavior |
| :--- | :--- | :--- | :--- |
| 21 | IMU begin fails | `IMUSensor::begin()` | Check SDA 21, SCL 22, power, address, and library |
| 22 | Sensor configuration fails | Enable/ODR/full-scale calls | Read the specific accelerometer or gyro error |
| 23 | Calibration has too few readings | `calibrateGyro()` | Check I2C; at least half the 500 samples must succeed |
| 24 | Calibration offsets vary | Gyro-bias averaging | Keep the sensor stationary for the sampling interval |
| 25 | Calibration failure does not halt setup | `setup()` | The sketch does not check `calibrateGyro()` return status |
| 26 | Pitch angle is noisy | `P.imuCutoff` | `IMUCUT` controls two cascaded pitch filters |
| 27 | Pitch response is delayed | `_filtAlpha` | Lower cutoff reduces noise but adds delay |
| 28 | Pitch-rate sign differs from pitch | `P.gyroSign`, `P.rateSign` | Check raw-axis and controller-frame signs separately |
| 29 | Sensor mounting axis is wrong | `PITCH_GYRO_AXIS`, accel axis macros | Axis selection remains compile-time |
| 30 | Mahony correction changes during motion | `currentKp` | Acceleration error above 0.2 g sets correction gain to 0.1 |
| 31 | Does compass data correct the quaternion? | Mahony block | Gravity correction uses accel/gyro; compass yaw is separate |
| 32 | Compass heading has an offset | `P.magOffX/Y/Z` | Inspect `MAGOFFX`, `MAGOFFY`, and `MAGOFFZ` |
| 33 | Compass axes are reversed | `P.magSignX/Y/Z` | Use the corresponding `MAGSGN` keys with ±1 |
| 34 | Compass init log appears with no sensor | `_compass.init()` | The log does not validate a successful detection |
| 35 | Does compass yaw steer the robot? | Heading block | Steering feedback is encoder differential |
| 36 | Angle remains unchanged after an I2C failure | `IMUSensor::update()` | Failed reads return early and retain previous measurements |
| 37 | O pitch differs from D pitchF | Odometry/debug blocks | O is raw filtered pitch; D applies TRIM and PITCHSGN |
| 38 | Left/right counts are zero | `setupPCNT()`, encoder pins | Check A/B wiring and both PCNT units |
| 39 | Right hardware count has opposite sign | `getPositionR()` | The getter negates right counts to match the left convention |
| 40 | Position scale is wrong | `params_recompute()` | Verify `WHEELR`, 4096 counts/revolution, and `COUNTSM` |

## Motors, drivers, and heading

| # | Question or symptom | Source | Check / behavior |
| :--- | :--- | :--- | :--- |
| 41 | Right driver COMM ERROR | `setupDriver()`, Serial2 | Check RX 16, TX 17, PDN_UART, TX resistor, and address straps |
| 42 | Left driver COMM ERROR | `setupDriver()`, Serial1 | Check RX 18, TX 19 and the same UART conditions |
| 43 | What does OK verify? | Connection and IFCNT check | Connection result zero and one counted write; inspect microstep readback |
| 44 | Driver error does not trigger MAIN warning | `StepperControl::begin()` | begin currently returns true regardless of per-driver results |
| 45 | One motor remains disabled | `MOTOR_EN_PIN` | Both enables must share GPIO 32; no separate left enable exists |
| 46 | Motor direction is reversed | `setSpeeds()` | Review LEFT/RIGHT_DIR_INVERT in config.h |
| 47 | Loaded current differs from compiled current | `setupDriver()`, `P.motorMa` | NVS CURRENT is used during driver initialization |
| 48 | M change disappears after reload | `setCurrent()` | M writes hardware only; use P,CURRENT,value |
| 49 | Driver temperature is high | CURRENT, supply, mechanics | Compare loaded current with motor rating and cooling |
| 50 | Motor skips under correction | MAXACC, MAXSPD | Inspect acceleration demand, supply, current, and mechanical drag |
| 51 | UART settings change but wheels do not move | STEP/DIR ISR | UART configures drivers; motion requires step pulses and enable |
| 52 | Timer API compile error | Core-version conditional | Use the Bluepad32 package; timer code has 2.x and 3.x paths |
| 53 | Wheel request exceeds common speed cap | Steering split | Steering is added after common velocity limiting |
| 54 | Final rate exceeds timer capability | `setSpeeds()` | Each wheel is clamped to ±TIMER_FREQ_HZ |
| 55 | Encoder overflow causes a discontinuity | `pcnt_overflow_isr()` | Check overflow extension at ±30000 counts |
| 56 | Short encoder pulses disappear | PCNT glitch filter | Pulses shorter than 1.25 microseconds are filtered |
| 57 | Heading corrections spin the robot | `dErr`, `diffRateF` | Check encoder direction, YAWKP/YAWKD, and YAWMAX |
| 58 | Heading abruptly re-latches | YAWRELCH, YAWTILT | Large differential error or tilt captures a new heading |
| 59 | Steering is too abrupt | `P.steerSlew` | STRSLEW limits active-steering rate changes |
| 60 | A look command turns while stationary | `lookCounts` | A,value adds a yaw reference through track width and encoder scale |

## Gamepad and host input

| # | Question or symptom | Source | Check / behavior |
| :--- | :--- | :--- | :--- |
| 61 | Gamepad will not connect | `btgamepad_begin()` | Use EVOFOX Home+B pairing mode and the Bluepad32 core |
| 62 | Pairing keys need clearing | BP32.forgetBluetoothKeys | Enable the existing call for one flash, then disable it |
| 63 | Buttons do nothing after connection | Center-calibration block | Both sticks must be near center before buttons are processed |
| 64 | START held while connecting does not arm | `_freshConnect` | First processed button levels are adopted, not treated as presses |
| 65 | SELECT must work independently of START | `_enableEvent` | SELECT emits an explicit stop event after connection/calibration |
| 66 | Which stick steers? | PAD_STEER_ON_LEFT_STICK | Default left X steers; right stick controls the camera |
| 67 | Steering is mirrored | `P.padStrSgn` | Set PADSTR to the appropriate ±1 sign |
| 68 | Forward is mirrored | `P.padFwdSgn` | Set PADFWD to the appropriate ±1 sign |
| 69 | Centered stick still drifts | Calibration and STICKDZ | Inspect captured offsets and active radial deadzone |
| 70 | PADDZ does not change response | `_shapeStick()` | Active mapping uses STICKDZ; the legacy _dz helper is unused |
| 71 | Centered stick produces invalid values | Radial rescaling | STICKDZ=0 permits division by zero at exact center |
| 72 | Steering snap produces invalid values | `_smoothstep()` | Keep SNAPOUT greater than SNAPIN |
| 73 | Steering is weak near straight travel | Snap taper | SNAPIN/SNAPOUT intentionally suppress lateral input near the forward axis |
| 74 | Input is gentle near center | `_expo()` | EXPOSTR and EXPODRV blend linear and cubic response |
| 75 | LB does not toggle stiff hold | Button mapping | LB toggles speed; D-pad UP toggles stiff hold |
| 76 | RB does not select HIGH speed | Button mapping | RB toggles the torch; LB toggles LOW/HIGH |
| 77 | Gamepad axes are ignored | Input arbitration | Fresh host V commands take priority, even with zero axes |
| 78 | V enable does not arm | `handleLine()` | Use START or E; only host 1-to-0 enable transitions request stopping |
| 79 | First V with en=0 does not stop balance | `radxaEnPrev` | There is no stop edge from the boot value 0; use X |
| 80 | Pad disconnect leaves balancing active | Disconnected input branch | Axes zero and timestamp expires; disconnect does not disarm |

## Parameters, serial, and auto-tuning

| # | Question or symptom | Source | Check / behavior |
| :--- | :--- | :--- | :--- |
| 81 | No reply to a command | `pollSerial()` | Use 460800 baud and LF or CR termination |
| 82 | Long commands are dropped | `rxBuf[96]` | Keep command text within 95 characters |
| 83 | Old dollar-prefixed commands fail | `handleLine()` | Send current command forms without a dollar prefix |
| 84 | P= changes the camera | Legacy tuner branch | P= is pan; use P,K1,value for a gain |
| 85 | How are valid parameter keys found? | `params_dump()` | P? reports keys, bounds, groups, descriptions, and derived values |
| 86 | There are more than 63 parameters | PARAM_TABLE | Current table has 106 fields across ten groups |
| 87 | Parameter editor splits descriptions incorrectly | P row format | Split only the first six commas; descriptions may contain commas |
| 88 | Parameter write is rejected | `params_set()` | Read PE for unknown key or out-of-range value |
| 89 | Invalid text is accepted as zero | `atof()` parsing | The parser does not validate numeric syntax before conversion |
| 90 | A bounded pair is inconsistent | Independent bounds | Min/max and SNAPIN/SNAPOUT relationships are not checked |
| 91 | Compiled changes have no effect after flash | `params_load()` | Saved NVS values override defaults; inspect P? |
| 92 | Defaults should replace saved values | `params_defaults()` | PD changes RAM; PS then persists it |
| 93 | PL without NVS does not undo edits | `params_load()` | With no saved version, current RAM values are retained |
| 94 | Saved settings survive reboot | Preferences namespace | PS writes each field under 2pybot with version 1 |
| 95 | K1= accepts values outside bounds | Legacy gain branch | Direct assignment bypasses bounds; use the P command |
| 96 | Wobble routine rejects starting | `AT,wobble` | Robot must already be balancing |
| 97 | Wobble reduction has stopped | RMS/iteration/floor checks | Target is 0.45 degrees RMS, eight reductions, or 40% gain floor |
| 98 | Trim routine aborts when input moves | `at_update()` | Wobble/trim abort on input above 0.05 or loss of balancing |
| 99 | AT,done reports busy during radius run | `at_handleLine()` | Busy guard executes before radius completion; manual calibration is needed |
| 100 | X fails to abort stall search | Idle motor-control path | Use AT,stop; balance stop does not cancel stall auto-tuning |

## Terrain, driver tuning, display, and payload

| # | Question or symptom | Source | Check / behavior |
| :--- | :--- | :--- | :--- |
| 101 | Auto-tune result is lost after reboot | `at_finish()` | Results are RAM-only until PS |
| 102 | Auto-tune times out | AT_TIMEOUT_MS | All active routines time out after 45 seconds |
| 103 | Terrain adaptation should be disabled | `P.terrEnable` | P,TERREN,0 resets reported roughness and multiplier |
| 104 | Roughness responds too slowly | `P.terrTau` | TERRTAU controls the EMA time constant |
| 105 | Rough-ground control feels softer | `terrain_soften()` | Normal K3/K4 and climb C3/C4 are multiplied by the terrain factor |
| 106 | Stiff hold ignores terrain softening | Stiff branch | S3/S4 are not multiplied by the factor |
| 107 | Airborne state appears | DROPG, DROPMS | Magnitude below 0.55 g for 35 ms confirms it by default |
| 108 | Gains stay soft after touchdown | LANDMS | Landing holds full softening for 350 ms by default |
| 109 | Integral still changes while airborne | Saturation/driving branches | AIRFRZ suppresses accumulation, not bleed or driving reset |
| 110 | Terrain rate data trails measurement | Main loop ordering | terrain_update currently receives the previous rateF |
| 111 | Saved StallGuard settings differ at boot | `setupDriver()` | Boot uses compiled tuning; PL after initialization applies saved settings |
| 112 | Runtime CoolStep disable is needed | `applyTuning()` | Set CSSEMIN to zero |
| 113 | DIAG never reports | USE_DIAG_PINS | Wire GPIO 34/35 and enable the compile-time option |
| 114 | DIAG reports but does not stop motors | Main-loop DIAG block | Reporting is intentionally separate from balance stop conditions |
| 115 | Disarmed motors do not hold | `disable()` | Shared EN is HIGH; standstill current settings do not keep drivers enabled |
| 116 | Ring points in the wrong direction | LEDFRONT, LED_DIR_CW | Set front index within the ring; direction remains compile-time |
| 117 | Ring refresh or brightness is wrong | LEDFPS, LEDBRI | Runtime defaults are 50 Hz and 200/255 |
| 118 | Host owns control without a red ring | Hazard condition | Red requires balancing, zero drive input, and speed above 0.10 m/s |
| 119 | Pan/zoom wiring follows old comments | config.h pins | Actual pins are pan 26, zoom 0, torch 2 |
| 120 | Pan request exceeds physical output | `_servoWriteDeg()` | Physical pulse conversion clamps to 180 degrees |
| 121 | Servo stops pulsing while idle | `P.svIdleMs` | SVIDLE above zero releases pulses after inactivity |
| 122 | SVRATE does not change servo PWM | Payload refresh gate | It changes write cadence; PWM remains 50 Hz |
| 123 | Saved torch boot preset is ignored | `_torchPct` initializer | Actual preset uses TORCH_BOOT_PCT, not P.torchBoot |
| 124 | Torch boot message contains wrong numbers | `payload_begin()` | Float P.torchBoot is passed to an integer printf format |
| 125 | Debug records arrive faster than 10 Hz | DEBUG_PERIOD_MS | Value 10 means nominal 100 Hz; L toggles periodic debug |
| 126 | Radxa gate uses the wrong velocity scale | radxa_brain.py constants | Match firmware baud and loaded wheel radius before using O records |

## Command references

- [USB protocol and telemetry](../../firmware/BaseLink/PROTOCOL.md)
- [Configuration and tuning](Config_and_Tuning_Guide.md)
- [Common troubleshooting](Troubleshooting_Guide.md)
- [Program flow](Program_Flow_State_Machine.md)

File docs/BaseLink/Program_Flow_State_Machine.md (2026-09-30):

# Program Flow and State Machine

Reference: [BaseLink.ino](../../firmware/BaseLink/BaseLink.ino). The balance state enum contains only `STATE_IDLE` and `STATE_BALANCING`.

## Boot sequence

1. Start USB serial at 460800 baud and wait 300 ms.
2. Load runtime parameters from NVS, or retain compiled defaults when no saved version exists. Apply `BOOTHIGH` to gamepad speed mode.
3. Initialize the LED ring and play its blocking startup animation.
4. Initialize I2C, IMU, and compass. Halt setup if IMU initialization returns false.
5. Disable the shared motor enable line, configure both TMC2226 drivers, initialize PCNT, and start the step timer.
6. Wait `STARTUP_SETTLE_MS`, default 3000 ms.
7. Average `GYRO_CAL_SAMPLES`, default 500, with 2 ms spacing. The sketch calls calibration but does not act on its return value.
8. Start Bluepad32 and initialize camera servos and torch.
9. Set the loop timestamp. Remain in `STATE_IDLE` until arming is requested.

Driver UART errors print `COMM ERROR`; `StepperControl::begin()` still returns true. The sketch's UART warning branch does not receive these individual failures.

## Loop order

The loop runs when at least 5000 microseconds have elapsed. `dt` uses that elapsed interval, capped at 0.05 s.

1. Read IMU data and calculate corrected pitch, terrain state, and pitch rate. Terrain currently receives the previous loop's `rateF`.
2. Read wheel counts, calculate position and encoder difference, and update filtered rates.
3. Poll USB commands and Bluepad32 input.
4. Consume gesture/hold-mode buttons and payload input. Update camera and torch independently of balance state.
5. Report optional DIAG changes and speed-mode LED events.
6. Consume START/SELECT events.
7. Select drive authority: fresh host, fresh gamepad, or zero.
8. Advance gesture playback; sufficiently large operator input cancels it.
9. Evaluate balance-state transitions and run the controller when balancing.
10. Advance auto-tuning.
11. Update the LED ring.
12. Emit odometry and optional debug records at their scheduled intervals.

## State transitions

| Current state | Condition | Action / next state |
| :--- | :--- | :--- |
| Idle | START or `E` | Set `motorsRequested`; stay idle until upright |
| Idle | Requested and `abs(pitchF) < P.armAngle` | Reset controller, enable motors, enter balancing |
| Balancing | `X`, SELECT, or host enable 1-to-0 | Clear request, synchronize gamepad armed state, disable motors, enter idle |
| Balancing | `abs(pitchF) > P.maxTilt` | Fall LED event, disable, enter idle |
| Balancing | `abs(rateF) > P.maxRate` | Fall LED event, disable, enter idle |
| Balancing | No stop condition | Run LQR/LQI and steering |

Default thresholds are 5 degrees to arm, 55 degrees for fall cutoff, and 450 degrees/s for the rate cutoff. After an automatic stop, a new START press or `E` request is needed.

`V` messages never request arming. A first host `en=0` does not stop balancing unless the previous host enable value was 1. Gamepad disconnect zeros its axes; it does not cause a balance-state transition.

## Controller reset

`resetController()` clears `vCmd`, `zInt`, and `uOut`; captures current position and encoder difference as references; and clears gestures, stiff hold, climb mode, and look input.

It runs on entry to balancing and on serial `R`. `R` does not turn motors off and does not restore parameter defaults.

## Auto-tune state is separate

`autotune.h` has idle, wobble, trim, radius, and stall modes. These are not balance states. Wobble and trim require balancing; stall search requires idle and can enable the motors itself.

`requestDisable()` does not cancel the auto-tune state. During stall search, use the implemented `AT,stop` path. Radius completion is currently blocked by the auto-tune busy check. See [configuration and tuning](Config_and_Tuning_Guide.md).

## Payload and display

Serial polling, sensors, camera controls, ring updates, and telemetry continue in idle. The torch starts off and is not switched off by `requestDisable()` in the current sketch. GPIO 2 is the torch pin, not an onboard blink indicator.

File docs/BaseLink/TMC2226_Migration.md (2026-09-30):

# TMC2226 Driver Migration and Current Setup

Reference: [stepper_control.cpp](../../firmware/BaseLink/stepper_control.cpp) and [config.h](../../firmware/BaseLink/config.h).

## Migration background

Earlier TMC2208 modules ran with an unreliable UART link, leaving current and microstep settings dependent on Vref and pin straps. Historical encoder tests showed 1/8 microsteps and a motor speed ceiling near 9000 microsteps/s at 1100 mA.

The migration repaired UART communication and moved to TMC2226, a TMC2209-register-compatible driver with StallGuard4 and CoolStep. Historical tests recorded similar speed ceilings in StealthChop and spreadCycle. Those measurements describe that hardware setup, not a guaranteed limit for another motor or supply.

## Current wiring

| Signal | Right | Left |
| :--- | :--- | :--- |
| STEP | GPIO 33 | GPIO 27 |
| DIR | GPIO 25 | GPIO 14 |
| EN | GPIO 32, shared active LOW | GPIO 32, shared active LOW |
| UART | Serial2 | Serial1 |
| UART RX / TX | GPIO 16 / 17 | GPIO 18 / 19 |
| Optional DIAG | GPIO 35 | GPIO 34 |

Both drivers use UART address 0 with MS1/MS2 LOW. Each TX line uses a 1 kOhm series resistor for the single-wire UART connection. `R_SENSE` is 0.11 ohm. The old separate left enable on GPIO 26 is no longer present; GPIO 26 is camera pan.

## Boot configuration

`setupDriver()` uses `TMC2209Stepper` for both TMC2226s. It:

1. Clears status flags and selects UART configuration for current and microsteps.
2. Applies loaded `P.motorMa`, default 1500 mA.
3. Programs 1/8 microsteps with internal interpolation enabled.
4. Sets standstill-current and power-down registers.
5. Selects StealthChop at all speeds by default.
6. Programs compile-time StallGuard and CoolStep settings.
7. Checks `test_connection()==0` and an IFCNT increment of one after a verification write.

Example at compiled defaults:

```text
[STEP] RIGHT TMC2226: OK | 1500 mA, 1/8 usteps (readback 1/8), StealthChop, SGTHRS=77, CoolStep ON
```

`COMM ERROR` reports a failed connection/write check. It does not verify every configuration register and does not halt the sketch. `StepperControl::begin()` currently returns true even when a driver check fails.

## Compile-time and runtime settings

| Compiled setting | Default | Runtime key |
| :--- | :--- | :--- |
| `DRV_UART_ADDR` | 0 | None |
| `DRV_STEALTHCHOP` | 1 | None |
| `MICROSTEPS` | 8 | None |
| `MOTOR_CURRENT_MA` | 1500 mA | `CURRENT` |
| `SGTHRS_LEFT` / `SGTHRS_RIGHT` | 76 / 77 | `SGTHRSL` / `SGTHRSR` |
| `DRV_TCOOLTHRS` | 300 | `TCOOL` |
| `COOLSTEP_ENABLE` | 1 | Runtime disable through `CSSEMIN=0` |
| `COOLSTEP_SEMIN` / `COOLSTEP_SEMAX` | 5 / 2 | `CSSEMIN` / `CSSEMAX` |
| `USE_DIAG_PINS` | 0 | None |
| `MAX_SPEED_STEPS` | 8500 microsteps/s | `MAXSPD` |
| `MOTOR_ACCEL_LIMIT` | 20000 microsteps/s² | `MAXACC` |

`applyTuning()` writes SGTHRS, TCOOLTHRS, SEMIN, and SEMAX to both drivers after parameter commands. `CURRENT` also writes RMS current. The first hardware callback is skipped at boot, and initial driver tuning still uses compiled values. Send `PL` after initialization to apply saved StallGuard/CoolStep settings.

Use `P,CURRENT,1500` for a persistent parameter-store change. Legacy `M=1500` only changes hardware current; `S` does not report current. `P?` reports the stored current setting, not driver readback.

## StallGuard and CoolStep

Both features require StealthChop on this driver family. StallGuard compares load measurements against SGTHRS and is speed-dependent through TCOOLTHRS. CoolStep adjusts current with a configured floor of half IRUN when active.

Optional DIAG interrupts count events. The main loop prints changes at most every 250 ms. DIAG is report-only; it does not stop the balance controller. When disarmed, the shared enable line is HIGH and the drivers are disabled, so standstill-current registers do not provide a disarmed hold mode.

## Motion and odometry

The driver UART configures the chips; it does not command wheel motion. A 20 kHz timer ISR emits STEP pulses from signed wheel rates. Motor direction inversion is set in `config.h`.

MT6816 encoders provide actual wheel counts through PCNT. Geometry conversion uses runtime `WHEELR`, now default 0.050 m. Microstep resolution changes require rebuilding and checking the conversion/control assumptions.

## Verification

1. Read each driver's boot result and 1/8 microstep readback.
2. Confirm both enable inputs share GPIO 32 and both motor directions agree on forward motion.
3. Inspect `P?`, then `PL` if saved runtime driver tuning should be applied.
4. Compare measured `velF` with common commanded speed in debug telemetry under steady motion.
5. Check current, speed, and acceleration against the actual motor/supply setup before raising limits.

The current `AT,stall` routine has an independent motor-control path and is not cancelled by `X` or SELECT. Its implemented abort is `AT,stop`; see [Configuration and Tuning](Config_and_Tuning_Guide.md).

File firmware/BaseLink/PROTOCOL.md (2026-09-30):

# BaseLink USB Serial Protocol

Reference: `BaseLink.ino::handleLine()`, `params.cpp`, and `autotune.h`.

## Transport

- USB `Serial`, **460800 baud**, 8N1.
- Newline-terminated text. The parser accepts LF or CR as a terminator.
- Receive buffer: 96 bytes, including the final null terminator. Keep commands within 95 characters.
- Use the uppercase command forms below. Parameter keys and auto-tune routine names are case-insensitive.
- There is no `$` prefix, Bluetooth serial command service, or ESP-NOW receive path.

The current [Radxa console](../../software/radxa/console/README.md) uses 460800 baud. The legacy desktop GUI and older Radxa brain still open at 115200; those host settings must be changed before they can communicate with this firmware.

## Unsolicited streams

| Record | Default rate | Meaning |
| :--- | :--- | :--- |
| `O` | 50 Hz | Encoder odometry and IMU orientation; emitted in both states |
| `D` | Nominal 100 Hz | Controller and terrain debug; enabled at boot, toggled by `L` |
| `[TAG] ...` | On events | Boot, state, gamepad, driver, and tuning logs |
| `A,...` | During auto-tune | Progress, completion, abort, or status |

### Odometry

```text
O,ms,encL,encR,pitchDeg,yawDeg
```

`encL` and `encR` are signed 64-bit encoder counts from `StepperControl`; the right getter already negates its hardware count. They do not include `P.encSign`. Pitch is filtered `imu.getPitch()`, before balance trim/sign correction. Yaw is tilt-compensated compass heading in degrees.

### Debug

```text
D,ms,pitchF,rateF,uOut,velF,ex,vCmdSteps,steerSteps,satV,satA,loopMaxUs,speedHi,balancing,cmdFwd,cmdSteer,accelMag,rough,soften,terrainState,drops
```

| Field | Units / meaning |
| :--- | :--- |
| `ms` | Milliseconds since boot |
| `pitchF`, `rateF` | Forward-positive degrees and degrees/s |
| `uOut`, `velF` | Acceleration in m/s², filtered velocity in m/s |
| `ex` | Unclamped `posM-xRef`, metres |
| `vCmdSteps`, `steerSteps` | Common and differential step rates, microsteps/s |
| `satV`, `satA` | Velocity/acceleration clamp flags |
| `loopMaxUs` | Largest measured loop interval since the previous debug record |
| `speedHi`, `balancing` | HIGH-speed flag and balance-state flag, 0 or 1 |
| `cmdFwd`, `cmdSteer` | Inputs after authority selection and gesture playback |
| `accelMag` | Acceleration magnitude in g |
| `rough`, `soften` | Roughness estimate and pitch-gain multiplier |
| `terrainState` | 0 flat, 1 rough, 2 airborne, 3 landing |
| `drops` | Confirmed airborne events since boot |

Parse comma-separated fields. Do not use the legacy tab-separated PID telemetry layout.

## Parameter commands

| Command | Reply | Action |
| :--- | :--- | :--- |
| `P?` | `P#,n`, parameter rows, derived rows, `P.` | Dump all settings |
| `P,key,value` | `P!,key,value` or `PE,reason` | Set one parameter within its bounds |
| `PS` | `PS!,saved` | Save the current parameter store to NVS |
| `PL` | `PL!,loaded from NVS` or `PL!,no NVS, using defaults` | Load NVS when present |
| `PD` | `PD!,defaults restored (not saved)` | Restore compiled defaults in RAM |

Other hardware/log records can appear before a parameter-command reply.

```text
P#,106
P,key,value,min,max,group,description
PR,STEPSM,value
PR,COUNTSM,value
PR,VMAX,value
PR,AMAX,value
P.
```

Split a parameter row at its first six commas; descriptions may contain commas. Derived fields are read-only. Changes to `WHEELR`, `MAXSPD`, or `MAXACC` recompute the conversion and limit chain.

| Group | Parameters |
| :--- | :--- |
| BALANCE | 15 |
| STEPPER | 9 |
| DRIVE | 17 |
| YAW | 10 |
| SAFETY | 5 |
| IMU | 14 |
| CLIMB | 8 |
| LED | 3 |
| PAYLOAD | 17 |
| TERRAIN | 8 |
| **Total** | **106** |

`params.h` is the complete key/bounds reference. The current Radxa console builds parameter rows from this metadata. It has tabs for nine parameter groups; TERRAIN parameters are exposed by the API but do not yet have a tab. The legacy desktop GUI does not implement this protocol.

The [Android app](../../software/android/README.md) receives parameters through the console API and derives its group list dynamically, including TERRAIN.

Writes reject unknown keys and out-of-range values. Numeric text is parsed with `atof`, so malformed text may become zero. Bounds are per parameter and do not enforce relationships between settings. `TORCH_MAX_PCT` remains a compile-time cap, not a runtime parameter.

## Drive, state, and expression commands

| Command | Action |
| :--- | :--- |
| `V,fwd,steer,en` | Update host drive input and timestamp; fwd/steer clamped to -1 through 1 |
| `E` | Request arming when upright |
| `X` | Stop balancing |
| `C` | Stop balancing and run blocking gyro-bias calibration |
| `R` | Reset controller reference, integral, velocity, steering, gestures, and hold modes; does not disarm |
| `S` | Print gains, state, speed/hold mode, and payload status |
| `L` | Toggle periodic debug records |
| `?` | Print command help |
| `G,yes` / `G,no` / `G,spin` / `G,dance` | Start a gesture while balancing and outside climb mode |
| `G,stop` | Stop gesture playback |
| `H,0` / `H,1` / `H,2` | Normal hold / stiff hold / climb mode |
| `A,value` | Heading look offset, clamped to -1 through 1 |
| `F` | Toggle torch |
| `N` | Center camera servos |
| `B=value` | Set torch brightness preset, clamped to runtime minimum and compile-time cap |
| `P=value` | Set requested pan angle |
| `Z=value` | Set requested zoom angle |

Fresh `V` messages override gamepad drive regardless of `en`. The enable field only triggers a balancing stop on a 1-to-0 transition. It never arms. A first `V,0,0,0` is therefore not an unconditional stop.

## Legacy tuning forms

`K1=value` through `K5=value` and `T=value` write the gain/trim fields directly. They bypass parameter bounds but share the same storage saved by `PS`. Prefer `P,K1,value` and `P,TRIM,value`.

`M=value` writes driver current directly without updating `P.motorMa`, bounds checking, or persistence. Use `P,CURRENT,value` for a parameter-store update.

`P=value` controls camera pan. It does not set a balance proportional gain. `I=value`, `D=value`, `$KP=...`, and keyboard `#` drive commands are not current balance commands.

## Auto-tune commands

| Command | Behavior |
| :--- | :--- |
| `AT,wobble` | Measure pitch RMS and reduce K3/K4 in bounded iterations; requires balancing |
| `AT,trim` | Average corrected pitch and adjust TRIM; requires balancing |
| `AT,radius` | Begin a wheel-radius measurement |
| `AT,done` | Intended radius completion; currently blocked by the busy guard during a radius run |
| `AT,stall` | Ramp raw wheel speed from idle and compare measured velocity |
| `AT,stop` | Abort the active routine and restore its saved gain/trim/speed values |
| `AT,?` | Report routine and step |

Routines time out after 45 seconds and do not save to NVS. Use `PS` to save a reviewed result. Wobble and trim abort when balancing stops or drive input exceeds 0.05. Radius and stall have different stop conditions.

Stall tuning drives motors while the balance state is idle. `X` and SELECT do not cancel it in the current code; `AT,stop` is its implemented abort command. See the [tuning guide](../../docs/BaseLink/Config_and_Tuning_Guide.md) for the remaining implementation limits.

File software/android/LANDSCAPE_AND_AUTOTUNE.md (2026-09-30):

# Landscape Layout and Auto-Tuning

Reference: `MainActivity.kt`, `TuneScreen.kt`, `AutoScreen.kt`, and `BotRepository.kt`.

## Landscape behavior

- Navigation changes from a bottom bar to a rail.
- The top app bar is hidden; stop control moves to the rail header.
- Live uses camera and status panes.
- Tune places parameter groups in a 132 dp left column and values on the right.
- Map uses separate trail and statistics areas.
- Auto places routine controls beside the progress log.

Portrait retains the bottom navigation and top stop action. Activity orientation is `fullSensor`, with configuration changes handled by the activity.

## Auto-tune transport

The app posts `AT,<routine>` through `/api/command`. The imported [Radxa server](../radxa/console/console/server.py) already includes `AT,` in its command-prefix whitelist.

Firmware `A,...` progress lines are forwarded by the console as log events. `BotRepository` filters them into the Auto log. Completed tuning values remain in RAM until Save sends `PS` through the console.

| Action | Firmware command | Current behavior |
| :--- | :--- | :--- |
| Wobble | `AT,wobble` | Measure pitch RMS; reduce K3/K4 in bounded steps while balancing |
| Trim | `AT,trim` | Average corrected pitch and adjust TRIM while balancing |
| Radius | `AT,radius` | Start a two-metre radius measurement |
| Done | `AT,done` | Currently intercepted by the firmware busy guard during radius measurement |
| Stall | `AT,stall` | Search raw motor speed from idle; UI asks for confirmation |
| Abort | `AT,stop` | Abort the active routine through its dedicated firmware path |
| Keep result | Parameter save action | Persist firmware settings to NVS |
| Discard | Parameter load action | Reload saved firmware values when present |

Wobble/trim require balancing. Stall/radius use different preconditions. The firmware timeout is 45 seconds.

The app stop control sends `X`, not `AT,stop`; it does not cancel stall tuning in the current firmware. App controls cannot correct this firmware limitation.

## Current parameter coverage

The Tune screen derives groups from received parameter metadata. It can render all **106** current fields, including the eight TERRAIN fields. The hint text remains defined for the original nine groups; TERRAIN uses the same generic row renderer.

Gains and TRIM now share the firmware `P` store used by serial tuning. The imported console still parses only the original 15 debug fields, so the five newer terrain telemetry fields are not yet available to this app.

See [the firmware tuning guide](../../docs/BaseLink/Config_and_Tuning_Guide.md) for limits and [the USB protocol](../../firmware/BaseLink/PROTOCOL.md) for commands.

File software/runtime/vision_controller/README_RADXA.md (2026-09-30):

# Radxa Vision Controller

`radxa_brain.py` provides a YOLOv4-tiny collision guard, person following, ArUco mode switching, and a browser camera stream. It communicates with BaseLink through USB `O` odometry and `V` drive messages.

The current Cubie console package is documented in [software/radxa/console](../../radxa/console/README.md). Both applications own the camera and serial port; run one at a time.

## Match the current firmware first

The checked-in brain still uses:

- 115200 baud in `open_port()`.
- `COUNTS_PER_M = 4096 / (2*pi*0.0350)`.
- `ENC_GUARD_SIGN=+1` for forward velocity.

Current BaseLink uses **460800 baud** and a compiled wheel radius of **0.050 m**. Match the brain's baud and geometry to the actual firmware/NVS settings before running it. Read `P?` from BaseLink to check `WHEELR` and `COUNTSM`; the brain does not request parameters automatically.

The brain's `V,...,1` messages request drive authority but do not arm current BaseLink. Arm with gamepad START or serial `E`. See the [firmware protocol](../../../firmware/BaseLink/PROTOCOL.md).

## Install on the Radxa

Copy the files from this directory:

```bash
scp radxa_brain.py get_models.sh radxa-brain.service radxa@<CUBIE_IP>:~/robot/
```

On the Radxa:

```bash
cd ~/robot
sudo apt update
sudo apt install -y python3-opencv python3-numpy python3-serial
bash get_models.sh
python3 radxa_brain.py --make-cards
```

OpenCV must include `cv2.aruco`. The model downloader fetches `yolov4-tiny.cfg`, `yolov4-tiny.weights`, and `coco.names` into the working directory. Card generation writes FOLLOW-ME marker 7 and STOP-FOLLOWING marker 8 from `DICT_4X4_50`.

## Run

```bash
python3 radxa_brain.py /dev/ttyUSB0
```

Open `http://<cubie-ip>:8080` for annotated video and FOLLOW/GUARD buttons. Camera discovery tries V4L2 devices 0 through 3 with MJPG, 640x480, and a small buffer. Serial is opened with an exclusive lock and DTR/RTS disabled.

The process must own its camera and serial port. To inspect existing users:

```bash
sudo fuser -v /dev/video0
sudo lsof /dev/ttyUSB0
```

Terminal commands are `f`, `g`, or `q` followed by Enter. Marker 7 selects FOLLOW; marker 8 selects GUARD. `--show` opens a local OpenCV window and requires a display. Without it, use the browser stream.

JPEGs are encoded only when a stream client is connected. Detection continues without a viewer.

## GUARD mode

GUARD starts silent so the gamepad can drive. It sends zero forward/steering commands when:

- A non-person detection in the center corridor is closer than `STOP_CM=70`, or an unknown object's box is wider than 45% of the frame.
- Encoder-derived forward velocity exceeds 0.05 m/s.
- Odometry is less than 0.5 s old.

It holds the zero command for at least one second and releases after the corridor has been clear for one second. Person detections are collected separately and do not trigger this guard-distance test.

Zero `V` commands stop the drive request while leaving balance armed. BaseLink's red hazard display appears only while balancing, with near-zero commanded motion and measured speed above 0.10 m/s. It need not remain red for the entire guard hold.

## FOLLOW mode

The brain selects the widest detected person box. It steers from horizontal center error and drives from width-fraction error relative to `TARGET_W_FRAC=0.34`.

- Forward request is limited to ±0.40 and steering to ±0.55.
- Commands are smoothed with coefficient 0.35.
- A forward obstacle or person wider than 55% of the frame sets the forward target to zero; command smoothing still applies.
- During a brief target loss, forward request is zero and the last smoothed steering request is halved. After 0.7 s without a person, transmission becomes silent.

BaseLink retains host authority until its freshness window expires, default 600 ms after the last `V` line. At the default `DRIVEV=0.70`, a 0.40 forward request corresponds to a 0.28 m/s velocity target. This is separate from the balancer's recovery speed ceiling.

## Wire behavior

An I/O thread sends active commands at 50 Hz. If the vision command becomes older than 0.5 s while transmission remains active, it sends `V,0,0,1`. It reads `O` records for average encoder position and filtered velocity; other serial records are ignored.

Switching to GUARD or quitting makes transmission silent. The GUARD/STOP button is a mode switch, not the firmware's `X` balancing stop.

## Settings

| Setting | Default | Purpose |
| :--- | :--- | :--- |
| `STOP_CM` | 70 | Known-object stop-distance threshold |
| `CORRIDOR` | 0.25 to 0.75 | Horizontal corridor by box-center fraction |
| `FOCAL_PX` | 600 | Width-based distance estimate |
| `TARGET_W_FRAC` | 0.34 | Desired apparent person width |
| `FWD_KP` / `FWD_MAX` | 2.2 / 0.40 | Following speed gain and request cap |
| `STEER_KP` / `STEER_MAX` | 1.4 / 0.55 | Following steering gain and request cap |
| `FOLLOW_STEER_SIGN` | +1 | Direction convention |
| `LOST_SILENT_S` | 0.7 | Target-loss timeout |

Distance estimates depend on assumed object widths and camera calibration. Person following uses apparent width, not measured range.

## Service

`radxa-brain.service` runs from `/home/radxa/robot` as user `radxa`, uses `/dev/ttyUSB0`, and restarts on failure. Adjust those values for the target device, then install:

```bash
sudo cp radxa-brain.service /etc/systemd/system/
sudo systemctl daemon-reload
sudo systemctl enable --now radxa-brain
journalctl -u radxa-brain -f
```

The working directory must contain the three model files. Under systemd, switch modes through the browser or ArUco cards.

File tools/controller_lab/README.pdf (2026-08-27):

# 2PYBOT LAB

## Balancing-Robot Simulation Workbench — Lab Manual

## Physics · LQR & PID control · fault injection · experiments · every setting explained

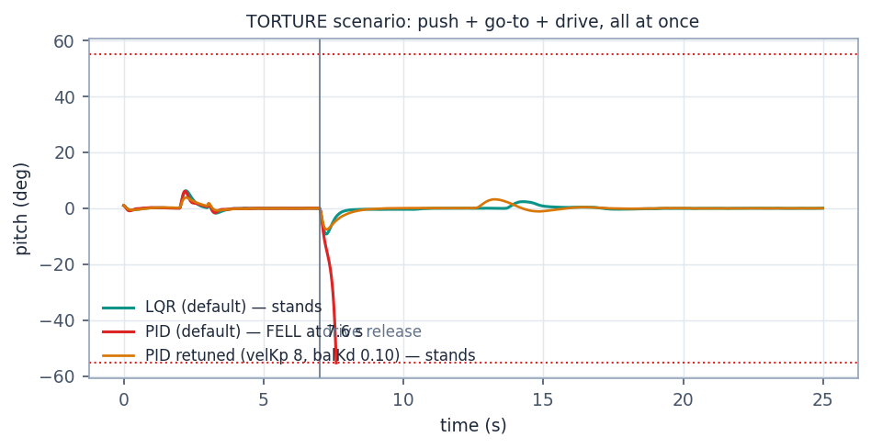
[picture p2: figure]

Figure 1. The experiment this tool exists for: identical torture test, three controllers. LQR stands untouched, default PID falls at the drive release, retuned PID recovers — the whole story of the project in one plot.

Applies to | 2pybot-lab.html v3 (single-file offline app, 3D viewport + video export)
Modeled robot | 2PyBot: ESP32 BaseLink · NEMA17 + TMC2208 steppers · MT6816 encoders 4096 CPR · ISM6HG IMU · 70 mm wheels
Engine validation | Riccati solver matches SciPy to 4 decimals; fault reproductions match the real robot's failures
Manual version | 1.0 — August 2026

2PYBOT LAB — LAB MANUAL | v1.0 · Aug 2026

# Contents

### 1 Introduction — what this lab is

### 2 Quick start (five minutes)

### 3 The machine and its physics

### 4 The simulation pipeline — what is actually modeled

### 5 The two controllers: LQR and PID

### 6 Tour of the interface

### 7 How to read the graphs (worked example)

### 8 Configuration reference — every parameter

### 9 Guided experiments E1–E10

### 10 Parameter sweeps — finding the cliff

### 11 Data export, sim video, and loading your CAD

### 12 Under the hood: fidelity, validation, limitations

### 13 Troubleshooting and FAQ

### 14 Glossary

# 1 Introduction — what this lab is

2PyBot Lab is a self-contained simulation workbench for a two-wheeled balancing robot. It runs the same control laws as the real 2PyBot firmware (BaseLink_LQR and BaseLink_PID), on a physics model that includes the unglamorous parts that actually decide whether a robot stands: sensor noise, filters, encoder quantization, actuator speed and acceleration limits, motor stall, control latency, and sign conventions. Every one of those imperfections is a knob you can turn.

The Lab exists because of a hard-won lesson: this robot's real failures were never exotic. They were

### an inverted gyro sign, a microstepping mismatch, and a motor stall — and each of those is

reproducible here, quantitatively. The simulated inverted-gyro robot whips over in 0.285 s; the real one did it in about 0.3 s. When a tool predicts your bugs that precisely, you can trust it to predict your fixes.

What you can do with it: design LQR gains for any geometry by solving the Riccati equation in the browser, tune the PID cascade by hand, replay every run as a live 3D animation, record simulation videos, compare runs against a pinned baseline, inject faults, and sweep any parameter to find exactly where a design breaks. It is one HTML file, works offline, and stores nothing outside your downloads.

# 2 Quick start (five minutes)

### 1. Open 2pybot-lab.html in any modern browser (Chrome or Edge recommended — required for

video export). The app immediately runs the default scenario: your robot, station keeping, LQR.

2. Watch the playback: the 3D robot twitches, catches its 1° initial tilt, and stands. The scope traces draw themselves; the verdict stamps STANDS with six metrics.
3. In the left rail open Fault injection, tick Invert gyro rate (bug), press RUN (or key R). Watch the robot whip itself over in a third of a second — this is the actual bug the real robot shipped with.
4. Untick the fault. Open Scenario, choose Push recovery, RUN. Drag the viewport to orbit the 3D camera while it recovers; scrub the timeline slider to inspect the exact moment the push lands.
5. Press Pin as baseline, switch the top-bar toggle to PID, RUN again. The dashed overlay is LQR; the amber trace is PID; the tiles show the deltas. You have now used every core workflow in the tool.

# 3 The machine and its physics

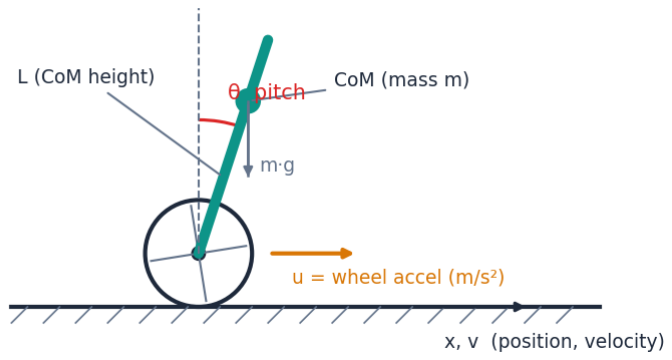
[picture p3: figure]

Figure 2. The model: an inverted pendulum whose pivot (the wheel axle) you can accelerate horizontally. Gravity torques the body away from upright; the only tool the controller has is wheel acceleration u.

The robot is an inverted pendulum on wheels. Its body pivots freely about the wheel axle; gravity constantly tries to tip it. The controller cannot push the body directly — it can only accelerate the wheels along the ground. Accelerating the wheels forward makes the body pitch backward relative to them (the same reason you lurch when a bus pulls away), and that coupling is the entire mechanism of balance: drive the wheels back under the falling body, always, 200 times per second.

## States

Symbo l | Name | Unit | Measured by
x | wheel position along the ground | m | encoders (4096 counts/rev, quantized)
v | wheel velocity | m/s | differenced encoder counts, low-pass filtered at 15 Hz
θ | body pitch from upright (+ = leaning forward) | rad (shown in deg) | IMU + Mahony fusion, two-stage 50 Hz filter
ω | pitch rate | rad/s (deg/s) | gyro, direct
z | integral of position error over time | m·s | computed by the controller

## Equations of motion (as simulated)

ω' = ( g·sin(θ) − a·cos(θ) ) / L | body angular acceleration
x' = v , | v' = a | wheel kinematics (stepper-driven)
a | = wheel acceleration actually delivered by the steppers

L is the height of the center of mass above the axle — the single most important number in the model. It sets the natural toppling rate √(g/L) ≈ 8.1 rad/s at L = 0.15 m: left alone, a small tilt grows e-fold every 0.12 s. Everything the controller does must be faster than that.

## Why this plant is genuinely hard: non-minimum phase

To move forward from rest, the robot must first lean forward; to lean forward, the wheels must first roll backward. So the correct response to “go right” begins with a small move left. Systems like this

### are called non-minimum phase, and they are why intuitive hand-tuning fights you: the

mathematically correct gains command initial motion that looks wrong. You can see the effect directly in Figure 8 (drive experiment): the wheels dip backward before every acceleration. It also explains why all five LQR gains come out negative — that is the physics, not a sign error.

# 4 The simulation pipeline — what is actually modeled

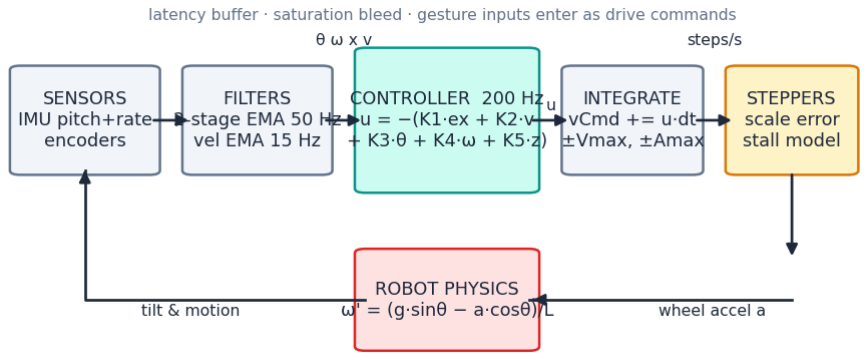
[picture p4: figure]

Figure 3. One control period (5 ms at 200 Hz). Physics integrates in 10 substeps between controller ticks. Every block in this chain is configurable, and every block has broken at least one real robot.

Stage | What the Lab models | Where configured
Pitch sensing | Gaussian angle noise + a constant CoG offset (the robot's true balance point is not the IMU's zero), then a 1- or 2-stage exponential filter at a settable cutoff. Filters add phase lag — stability costs. | Sensors & timing
Rate sensing | Gyro noise + constant bias. Sign can be inverted as a fault. | Sensors, Faults
Odometry | Position quantized to encoder counts; velocity from differenced counts through a low-pass. Sample dropout injectable. Sign invertible as a fault. | Sensors, Faults
Controller | LQR full-state feedback with integral action, or the PID cascade — the exact firmware structures, including position-error clamp, integral clamps, and the saturation ground-giving safeguard. | LQR / PID panel
Latency | The control output can be delayed N ms (buffer), emulating slow loops or communication lag. | Motor & drive
Actuator | u integrates into a velocity command, clamped to the speed cap; the wheel slews toward it under the acceleration limit. A scale error multiplies real motion per commanded step (microstep mismatch). Above the stall speed the motor loses sync: torque vanishes and the wheel spins down until the command returns below recovery. | Motor & drive
Disturbances | Rate impulses (pushes), continuous random gusts, initial tilt, and the scenario timeline. | Scenario

### Determinism: the noise generator is seeded (Simulation → Noise seed), so a run is exactly

repeatable — change one parameter and any difference you see is caused by that parameter, not by luck. Change the seed to check that a marginal design is not just a lucky roll.

# 5 The two controllers: LQR and PID

## 5.1 LQR — Linear Quadratic Regulator (with integral action)

u = −( K1·ex + K2·v + K3·θ + K4·ω + K5·z )
ex = clamp(x − x_target, ±0.15 m) | z = ∫ ex dt (clamped)

One line, five feedback terms, each watching one state. The magic is where the K values come from: you do not choose them. You choose weights — how much you dislike each kind of error (Q1…Q5)

### and how much you dislike motor effort (R) — and the solver computes the gain vector that

minimizes the total lifetime cost. That computation (the algebraic Riccati equation, solved in the app by Newton iteration seeded with pole placement) produces gains that are consistent with each other by construction, which is precisely what hand-tuning five coupled knobs cannot guarantee.

Gain | Watches | Acts like | Default (this robot)
K1 | distance from target | spring to the hold spot | -12.74
K2 | wheel velocity | damping on travel | -10.70
K3 | pitch angle | the main upright spring | -48.28
K4 | pitch rate | shock absorber on tilt | -6.01
K5 | accumulated position error | slow, patient drift-killer (this is the “I” in LQI) | -4.47

Workflow: set your robot's L in Robot model, set Q and R in the LQR panel, press Solve Riccati → K, and watch the Newton iterations converge (13 steps for the default). The closed-loop poles then appear as chips: every pole must be negative (green). Poles are the decay rates of the balanced system — the default set is −17.6, −7.8, −1.73 ± 0.87j, −0.57, meaning a fast tilt-catch layer, a medium recovery layer, and a slow, gentle position layer. A pole at −2 halves its error every 0.35 s; more negative = faster but hungrier for actuator. All K fields stay editable if you want to hand-perturb the optimum and watch what breaks.

## 5.2 PID — the classical cascade

vRef | = clamp( posKp · (x_target − x), ±vHoldMax ) | position loop
pitchRef = clamp( velKp·(vRef − v) + velKi·∫(vRef − v)dt ) | velocity loop
u | = balKp·(θ − pitchRef) + balKd·ω | angle loop

Three nested loops: position asks for a velocity, velocity asks for a lean, lean asks for wheel acceleration. Each loop must be substantially slower than the one inside it or they fight. The Lab's defaults stand comfortably in every single scenario except Torture — deliberately kept that way, because re-tuning PID to survive Torture (Experiment E5) teaches more about cascade controllers than any paragraph can.

## 5.3 Which to use

Use the Lab's baseline-pinning to answer this empirically rather than religiously. Broadly: LQR wins when you can measure your robot (L, mainly) and want coordinated aggression with robustness margins; PID wins when you have no model at all and are willing to iterate. On the real 2PyBot, LQR balanced on roughly the second attempt after a thousand failed PID hand-tunes — but note that the old firmware's PID also had a structurally broken architecture, so the fair fight is the one you can run here.

# 6 Tour of the interface

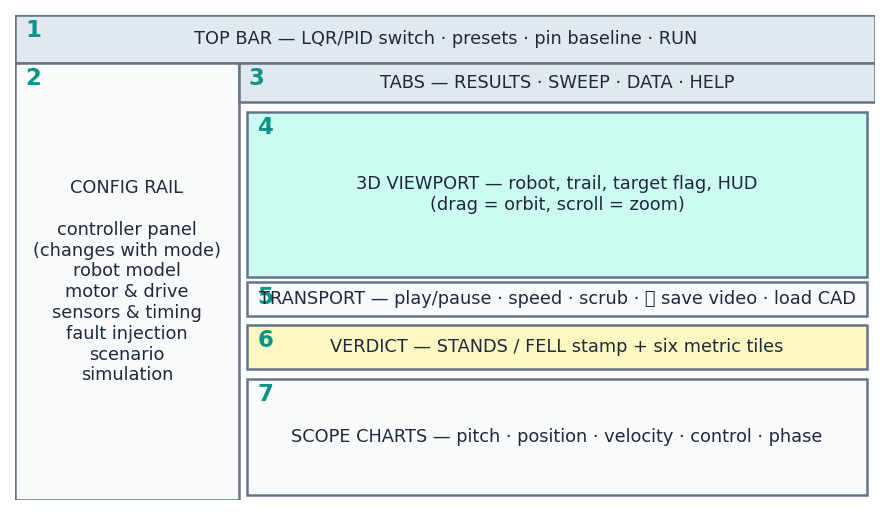
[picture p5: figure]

Figure 4. The seven regions of the app. The accent color follows the controller: teal = LQR, amber = PID.
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

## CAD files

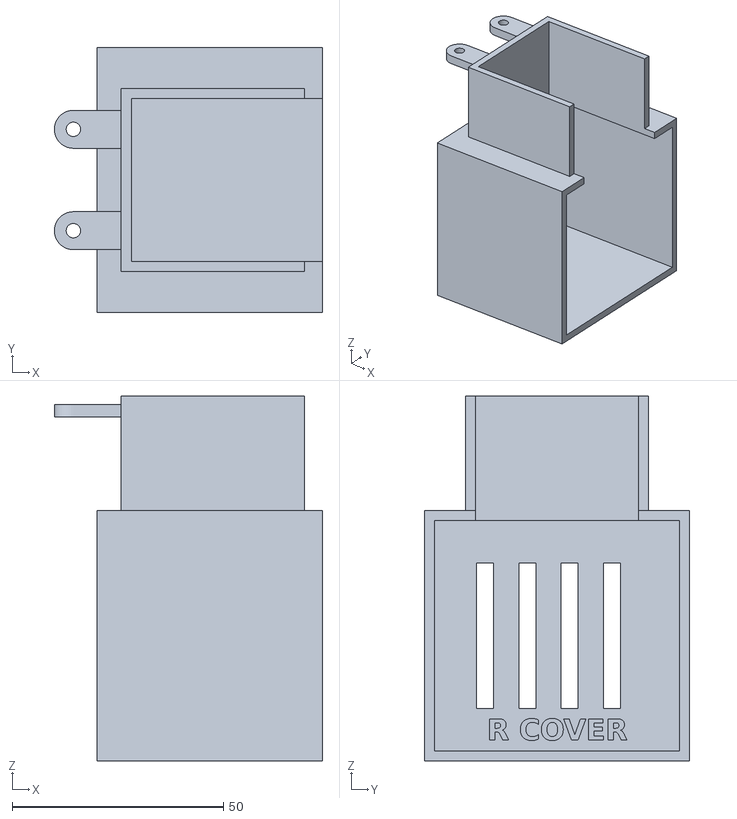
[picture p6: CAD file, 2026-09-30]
hardware/cad/enclosure/rev5/motor_R.stl
63.5 x 62.8 x 86.4

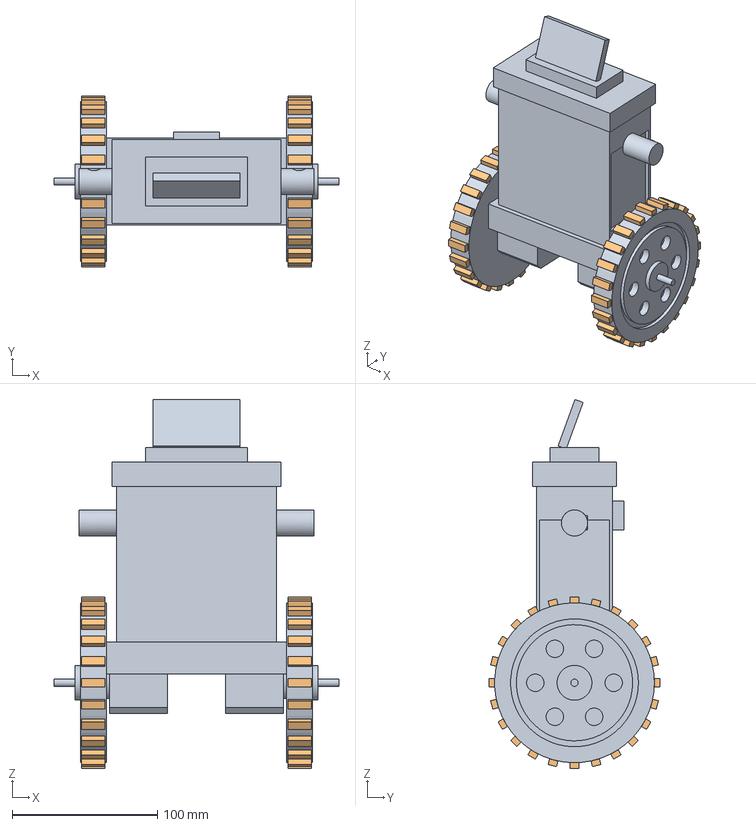
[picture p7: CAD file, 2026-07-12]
models/2pybot_simplified.step
196.0 x 118.0 x 254.0 mm

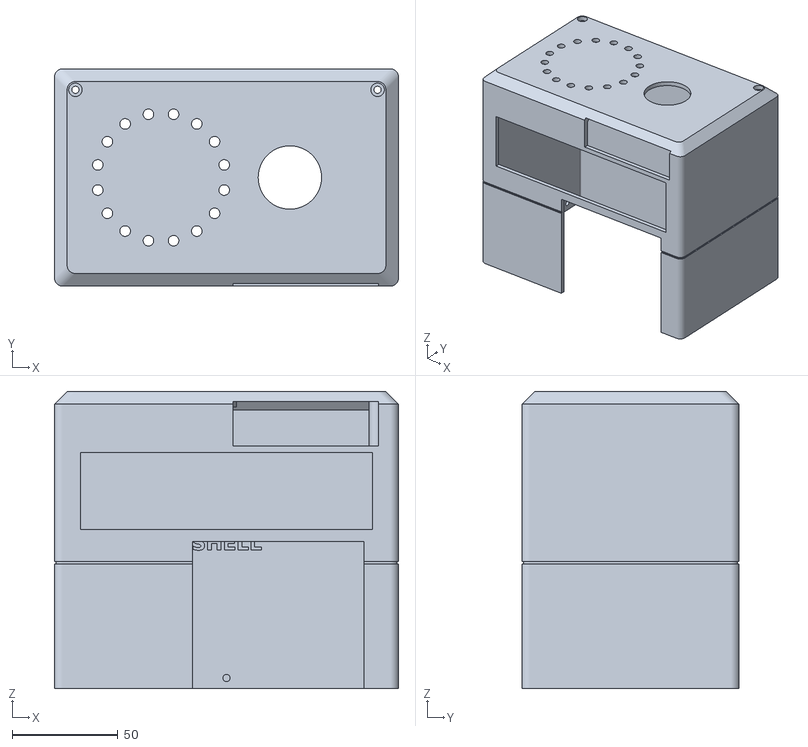
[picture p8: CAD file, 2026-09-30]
hardware/cad/enclosure/rev5/shell.stl
162.8 x 102.8 x 140.6

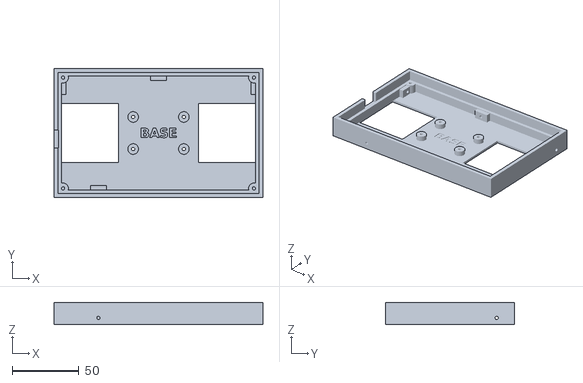
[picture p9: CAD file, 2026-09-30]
hardware/cad/enclosure/rev5/base.stl
156.6 x 96.6 x 16.6

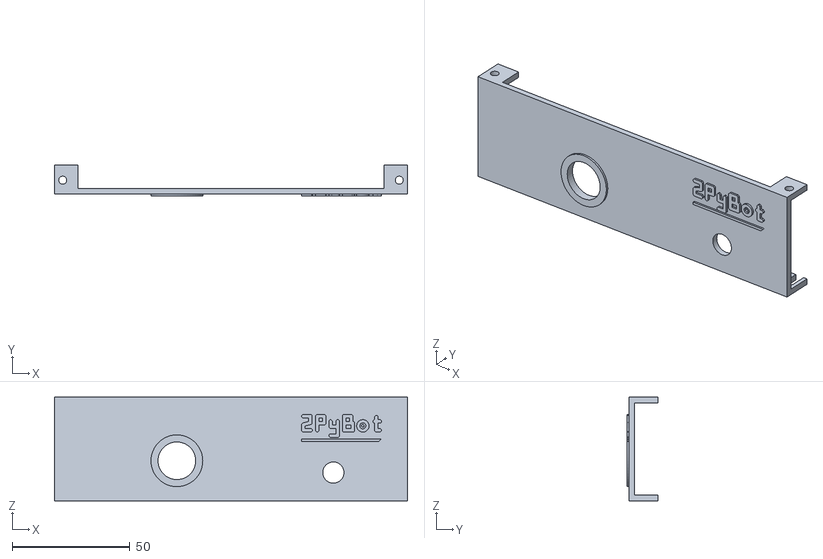
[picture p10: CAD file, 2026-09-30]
hardware/cad/enclosure/rev5/face.stl
150.0 x 13.3 x 44.0

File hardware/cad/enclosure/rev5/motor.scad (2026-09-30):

// 2PyBot motor cover (L/R). Two sections: upper spacer shroud + lower motor box.
// Wheel side OPEN. Fit: slide OUTBOARD over motor + standoffs, then push UP (LIFT)
// so the spigot seats in the tray's square opening; 2 M3 self-taps up into tray bosses.
// render: openscad -D 'side="L"' -o motor_L.stl motor.scad
include <dims.scad>
side="L";
UX0=SQ_X0+FIT; UX1=SQ_X0+SQ-FIT; UY0=SQ_Y0+FIT; UY1=SQ_Y0+SQ-FIT;   // spigot/shroud outer
UZ1=TRAY_Z0+FLOOR;                                                  // spigot top (in floor)
LZ1=FLANGE_Z+LIFT+0.5;                                              // lower box inner top
LZ0=M_BOT_Z-1-LIFT;                                                 // lower box inner bottom
module body(){
  difference(){
    union(){
      // lower motor box
      translate([M_X0,M_Y0-MW,LZ0-MW]) cube([M_X1-M_X0+MW,M_Y1-M_Y0+2*MW,LZ1-LZ0+2*MW]);
      // upper shroud (3 walls, outboard open)
      translate([UX0,UY0,LZ1]) cube([UX1-UX0,UY1-UY0,UZ1-LZ1]);
      // screw tabs from shroud inboard wall
      for(y=MTAB_Y) hull(){
        translate([MTAB_X,y,TRAY_Z0-3]) cylinder(d=9,h=3);
        translate([UX1-0.01,y-4.5,TRAY_Z0-3]) cube([1,9,3]);
      }
    }
    translate([M_X0-1,M_Y0,LZ0]) cube([M_X1-M_X0+1,M_Y1-M_Y0,LZ1-LZ0]);                // motor cavity
    translate([M_X0-1,UY0+MW,LZ1-1]) cube([UX1-MW-M_X0+1,UY1-UY0-2*MW,UZ1-LZ1+2]);    // shroud bore, open outboard
    for(y=MTAB_Y) translate([MTAB_X,y,TRAY_Z0-5]) cylinder(d=CLR,h=7);
    for(i=[0:3]) translate([M_X1-1,M_Y0+10+i*10,LZ0+10]) cube([MW+2,4,LZ1-LZ0-20]); // inboard vents
  }
}
if(side=="R") difference(){ translate([PCB_W,0,0]) mirror([1,0,0]) body();
  translate([PCB_W-M_X1-0.6,(M_Y0+M_Y1)/2,LZ0+5]) rotate([90,0,90]) id_text("R COVER",5); }
else difference(){ body();
  translate([M_X1+0.6,(M_Y0+M_Y1)/2,LZ0+5]) rotate([90,0,-90]) id_text("L COVER",5); }

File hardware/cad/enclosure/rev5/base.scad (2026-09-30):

// 2PyBot base / solder tray. PCB drops in (0.3/side), rests on ledge + 4 corner posts,
// M3 self-tap through the PCB corner holes into the posts.
include <dims.scad>
module tray(){
  difference(){
    union(){
      difference(){
        translate([TX0,TY0,TRAY_Z0]) cube([TX1-TX0,TY1-TY0,TRAY_Z1-TRAY_Z0]);
        translate([-FIT,-FIT,0]) cube([PCB_W+2*FIT,PCB_D+2*FIT,50]);                     // board well
        translate([-FIT+LEDGE,-FIT+LEDGE,TRAY_Z0+FLOOR]) cube([PCB_W+2*FIT-2*LEDGE,PCB_D+2*FIT-2*LEDGE,RECESS+0.01]);
      }
      for(c=CORNERS) translate([c[0],c[1],TRAY_Z0]) cylinder(d=8,h=-TRAY_Z0);            // corner posts
      for(b=BOSSES) boss_pad(b);                                                          // inward screw pads (below board)
      for(s=["L","R"]) for(y=MTAB_Y) translate([mx(MTAB_X,s),y,TRAY_Z0]) cylinder(d=8,h=FLOOR+4);
    }
    for(c=CORNERS) translate([c[0],c[1],TRAY_Z0+FLOOR]) cylinder(d=PILOT,h=20);
    for(b=BOSSES) boss_hole(b);
    for(s=["L","R"]){
      translate([s=="L"?SQ_X0:PCB_W-SQ_X0-SQ,SQ_Y0,TRAY_Z0-1]) cube([SQ,SQ,FLOOR+1.01]);   // big square
      for(y=MTAB_Y) translate([mx(MTAB_X,s),y,TRAY_Z0-1]) cylinder(d=PILOT,h=FLOOR+5);
    }
    translate([PCB_W/2,PCB_D/2,TRAY_Z0+FLOOR-0.6]) id_text("BASE",7);
    // USB-C: open-top U-notch in the LEFT wall so the board + receptacle drop in
    translate([TX0-1,USB_YC-USB_OW/2,USB_Z-USB_OH/2]) cube([TWALL+FIT+1,USB_OW,50]);
  }
}
module boss_pad(b){
  if(b[2]=="F") translate([b[0]-6,-FIT,TRAY_Z0]) cube([12,6,-TRAY_Z0-0.5]);
  if(b[2]=="B") translate([b[0]-6,PCB_D+FIT-6,TRAY_Z0]) cube([12,6,-TRAY_Z0-0.5]);
  if(b[2]=="L") translate([-FIT,b[1]-6,TRAY_Z0]) cube([6,12,-TRAY_Z0-0.5]);
  if(b[2]=="R") translate([PCB_W+FIT-6,b[1]-6,TRAY_Z0]) cube([6,12,-TRAY_Z0-0.5]);
}
module boss_hole(b){
  r = b[2]=="F"?[-90,0,0]: b[2]=="B"?[90,0,0]: b[2]=="L"?[0,90,0]:[0,-90,0];
  translate([b[0],b[1],BOSS_Z]) rotate(r) translate([0,0,-1]) cylinder(d=PILOT,h=10);
}
tray();

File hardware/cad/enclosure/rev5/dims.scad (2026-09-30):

// 2PyBot shared dimensions. ONE frame for every part:
// origin = bottom-deck FRONT-LEFT corner, z=0 = bottom-deck SOLDER (under) face.
// +X = left->right (viewed from front), +Y = front->back, +Z up.
// [ROUGH] = placeholder, fine-tune later.
$fn = 48;
PCB_W=150; PCB_D=90; PCB_T=1.6;
GAP_BOT=60; GAP_CAM=40;                       // bottom->mid, mid->top (clear gap)
Z_MID0=PCB_T+GAP_BOT; Z_MID1=Z_MID0+PCB_T;
Z_TOP0=Z_MID1+GAP_CAM; Z_TOP1=Z_TOP0+PCB_T;
HOLE_IN=3.5; HOLE_D=3.2;                      // corner M3 [ROUGH photo est.]
CORNERS=[[HOLE_IN,HOLE_IN],[PCB_W-HOLE_IN,HOLE_IN],[HOLE_IN,PCB_D-HOLE_IN],[PCB_W-HOLE_IN,PCB_D-HOLE_IN]];
// fits
FIT=0.3;          // locating / sliding fit per side
PILOT=2.5;        // M3 self-tap pilot
CLR=3.4;          // M3 clearance
// USB-C (Radxa power) on bottom deck, LEFT (X=0) edge — LOCKED
USB_Y0=PCB_D-54; USB_Y1=PCB_D-45; USB_Z=4.5;  // centre height above solder face
PLUG_W=12.5; PLUG_H=10;                        // cable housing
USB_OW=PLUG_W+1.0; USB_OH=PLUG_H+1.0;          // opening
USB_YC=(USB_Y0+USB_Y1)/2;
// motor standoffs (brass M3 hex) — SQUARE pattern, 4 per motor [ROUGH]
SO_C=[23,45]; SO_S=30;                          // centre (left motor), side
SO_X=[SO_C[0]-SO_S/2,SO_C[0]+SO_S/2]; SO_Y=[SO_C[1]-SO_S/2,SO_C[1]+SO_S/2]; SO_LEN=40;
SQ=44;                                          // big square opening in tray floor per motor
SQ_X0=SO_C[0]-SQ/2; SQ_Y0=SO_C[1]-SQ/2;
MTAB_X=56; MTAB_Y=[33,57];                      // cover screw tabs (left), self-tap up into tray
function mx(x,s)= s=="L"? x : PCB_W-x;         // mirror left->right
// base tray
FLOOR=2; RECESS=7; TWALL=3; TWALL_UP=6;        // wall rises 6 above board top
LEDGE=2.5;
TRAY_Z0=-(RECESS+FLOOR); TRAY_Z1=PCB_T+TWALL_UP;
TX0=-FIT-TWALL; TX1=PCB_W+FIT+TWALL; TY0=-FIT-TWALL; TY1=PCB_D+FIT+TWALL;
BOSS_Z=-4;                                     // shell->tray horizontal screws
// [x,y,normal] side boss points on tray outer walls
BOSSES=[[30,TY0,"F"],[PCB_W/2,TY1,"B"],[TX0,80,"L"],[TX1,80,"R"]];
// shell
SW=2.8; SFIT=0.3; SHROUD=24; LID_T=2.8;
SX0=TX0-SFIT; SX1=TX1+SFIT; SY0=TY0-SFIT; SY1=TY1+SFIT;
SZ0=TRAY_Z0; LID_Z0=Z_TOP1+SHROUD; SZ1=LID_Z0+LID_T;
// motor (NEMA17) [ROUGH]
NEMA=42.3; MW=2.4; LIFT=3;
FLANGE_Z=-SO_LEN;                               // bracket flange top
M_BOT_Z=FLANGE_Z-3-44;                          // lowest point (encoder board 44 sq)
M_X0=-3; M_X1=48;                               // bracket plate (wheel side) .. encoder pins
M_Y0=SO_C[1]-29; M_Y1=SO_C[1]+29;               // incl. side JST connector
ID_FONT="DejaVu Sans:style=Bold";
module id_text(t,s=5){ linear_extrude(0.61) text(t,size=s,font=ID_FONT,halign="center",valign="center"); }

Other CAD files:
hardware/cad/enclosure/rev5/motor_L.stl
hardware/cad/enclosure/rev5/face.scad
hardware/cad/enclosure/rev5/logo.scad
hardware/cad/enclosure/rev5/shell.scad

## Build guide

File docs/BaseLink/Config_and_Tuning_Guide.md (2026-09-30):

# Configuration and Tuning Guide

Reference: [config.h](../../firmware/BaseLink/config.h), [params.h](../../firmware/BaseLink/params.h), [params.cpp](../../firmware/BaseLink/params.cpp), and [BaseLink.ino](../../firmware/BaseLink/BaseLink.ino).

## Defaults, live settings, and saved settings

`config.h` defines pins, sensor axes, peripheral frequencies, and compiled defaults. `params.h` exposes 106 runtime fields. The controller and peripheral modules read the shared `P` store.

At boot, saved NVS values replace defaults when the stored version is recognized. Changing `config.h` does not override an existing saved value.

Connect USB serial at **460800 baud** with newline termination:

```text
P?
P,TRIM,0.071
P,CURRENT,1500
PS
```

The [Radxa console](../../software/radxa/console/README.md) provides the current browser parameter editor and NVS actions. It owns the USB connection while running. TERRAIN keys are available through its API; the browser terrain tab is pending.

- `P?`: current values, bounds, descriptions, and derived conversions.
- `P,key,value`: bounded write; read the `P!` or `PE` reply.
- `PS`: save to NVS.
- `PL`: reload NVS. If no saved version exists, current RAM values are retained.
- `PD`: reset RAM to compiled defaults. Follow with `PS` to replace saved settings.

Legacy `K1=` through `K5=` and `T=` bypass bounds. `M=` changes hardware current without updating the saved parameter field. Prefer the `P,` forms. `P=` now controls camera pan, not a PID gain.

## Hardware and geometry

| Setting | Default | Runtime key |
| :--- | :--- | :--- |
| Shared active-low motor enable | GPIO 32 | Compile-time |
| Motor microsteps | 8 | Compile-time |
| Encoder counts/revolution | 4096 | Compile-time |
| Wheel radius | 0.050 m | `WHEELR` |
| Track width | 0.155 m | `TRACKW` |
| Motor current | 1500 mA | `CURRENT` |
| Common speed ceiling | 8500 microsteps/s | `MAXSPD` |
| Acceleration ceiling | 20000 microsteps/s² | `MAXACC` |
| Full forward command | 0.70 m/s | `DRIVEV` |
| Step timer | 20 kHz | Compile-time |

The radius default corresponds to a 100 mm diameter, despite the older 70 mm comment in `config.h`. Use the loaded radius for odometry calculations. At default geometry, `STEPSM` is about 5093, `COUNTSM` 13038, `VMAX` 1.67 m/s, and `AMAX` 3.93 m/s².

The final left/right split includes steering and is separately limited by the timer frequency. `MAXSPD` is the common velocity ceiling, not a final per-wheel clamp.

## Verify signs before tuning gains

1. Read debug `pitchF` and `rateF` with the motors disabled. Forward tilt and forward rotation should produce positive values in the controller frame.
2. Push both wheels forward and inspect `O` counts. The right count is already negated in the getter. Inspect `velF` for the effect of `ENCSGN`.
3. Verify motor direction with a supported chassis. `LEFT_DIR_INVERT` and `RIGHT_DIR_INVERT` are compile-time flags.
4. Verify left-stick forward and steering direction. `PADFWD` and `PADSTR` are runtime signs.

Use exactly -1 or +1 for sign fields. Their numeric bounds allow intermediate values, but those values scale the measurements instead of simply changing direction.

## Balance parameters

| Keys | Default | Purpose |
| :--- | :--- | :--- |
| `K1` to `K5` | -7.0547, -6.5334, -34.5881, -4.2854, -2.1082 | Normal LQI gain vector |
| `TRIM` | 0.071 degrees | Pitch offset before controller sign correction |
| `ZLIM` | 0.5 m·s | Normal integral clamp |
| `EXCLAMP` | 0.15 m | Position-error/reference bound |
| `VSATBLD` | 3/s | Reference bleed near velocity saturation |
| `BRAKELK` | 0.30 s | Driving hold-reference lookahead |
| `S1` to `S5` | See `config.h` | Stiff-hold gain vector |
| `C1` to `C5` | See `config.h` | Climb gain vector |
| `CLMBZ` / `CLMBV` / `CLMBSTR` | 2.0 / 0.25 / 0.40 | Climb integral bound, reference speed, steering scale |

Start with correct geometry, signs, current, and filter settings. Check saturation flags before attributing drift or oscillation to gains. Change one setting at a time and compare pitch, velocity, position error, and loop timing.

`H,1` selects stiff hold and captures current position. `H,2` selects climb reference tracking. `H,0` returns to normal hold. Arming resets both mode flags, so select a hold mode after arming.

## Input shaping and heading

| Keys | Default | Effect |
| :--- | :--- | :--- |
| `STICKDZ` | 0.10 | Circular deadzone with range rescaling |
| `SNAPIN` / `SNAPOUT` | 10 / 26 degrees | Zero-to-full steering taper away from straight drive |
| `EXPOSTR` / `EXPODRV` | 0.65 / 0.35 | Cubic/linear response blend |
| `LOWDRV` / `LOWSTR` | 0.50 / 0.50 | LOW-mode gamepad authority |
| `BOOTHIGH` | 0 | Speed mode chosen at boot |
| `DRIVEDB` / `STRDB` | 0.03 / 0.05 | Drive-mode and steering thresholds |
| `MAXSTR` / `STRSLEW` | 6000 / 15000 | Differential rate cap and slew, in step-rate units |
| `YAWKP` / `YAWKD` | 1.5 / 0.02 | Encoder-difference heading gains |
| `YAWMAX` | 1200 | Heading-hold correction cap |
| `YAWRELCH` / `YAWTILT` | 2000 counts / 12 degrees | Heading re-latch conditions |

Keep `STICKDZ` above zero and `SNAPOUT` greater than `SNAPIN`. The current code permits values that cause zero denominators. `PADDZ` is retained in the table but the active radial mapping uses `STICKDZ`.

Keep both sticks centered on connection. Center calibration returns before button handling until all axes are within 0.25 of the estimated center. LOW mode only reduces gamepad drive authority; host commands, gestures, and balance recovery are not scaled by it.

## IMU and terrain

| Keys | Default | Purpose |
| :--- | :--- | :--- |
| `IMUCUT` | 50 Hz | Two-stage pitch filter cutoff |
| `MAHKP` / `MAHKI` | 2.0 / 0.005 | Mahony gravity-correction gains |
| `MAGOFFX/Y/Z`, `MAGSGNX/Y/Z` | 0 offsets, +1 signs | Compass correction |
| `TERREN` | 1 | Terrain adaptation enabled |
| `TERRTHR` / `TERRSOFT` | 0.18 / 0.55 | Roughness scale and minimum gain multiplier |
| `TERRTAU` | 0.35 s | Roughness filter time constant |
| `DROPG` / `DROPMS` | 0.55 g / 35 ms | Airborne confirmation |
| `LANDMS` | 350 ms | Softened-gain interval after touchdown |
| `AIRFRZ` | 1 | Suppress airborne integral accumulation |

`C` stops balancing and performs stationary gyro calibration. It does not reset the Mahony quaternion or save bias to NVS. Lowering `IMUCUT` smooths pitch but adds control delay.

Terrain adaptation scales normal K3/K4 and climb C3/C4. Stiff-hold gains are unaffected. Use `P,TERREN,0` for a flat-ground comparison. Airborne detection uses acceleration magnitude, not a wheel contact sensor.

## Driver, ring, and payload tuning

- `SGTHRSL`, `SGTHRSR`, `TCOOL`, `CSSEMIN`, and `CSSEMAX` are applied over driver UART on parameter writes. `CSSEMIN=0` disables CoolStep at runtime.
- Saved driver tuning is not applied by initial driver setup; send `PL` after boot to apply it. Loaded `CURRENT` and `IMUCUT` are used by their initialization paths.
- `LEDBRI`, `LEDFRONT`, and `LEDFPS` control ring brightness, mounting reference, and refresh rate. Use a front index within the physical 16-LED ring.
- Servo travel, home positions, pulse widths, rates, and idle release are runtime parameters. Keep minimum below maximum. Physical pulse output clamps to 0 through 180 degrees.
- `SVRATE` changes how often software writes servo duty; it does not change the fixed 50 Hz PWM carrier.
- `TRCHSTP` and `TRCHMIN` affect torch adjustment. `TRCHBOOT` is exposed but the actual preset still initializes from `TORCH_BOOT_PCT`.

## Auto-tune routines

| Command | Current implementation |
| :--- | :--- |
| `AT,wobble` | Uses 1.5 s pitch-RMS windows; multiplies K3 by 0.93 and K4 by 0.88 when needed; up to eight reductions and a 40% magnitude floor |
| `AT,trim` | Averages pitch in 4 s windows, adjusts TRIM, up to three passes |
| `AT,radius` | Starts a two-metre measurement; completion currently fails because `AT,done` is behind the busy guard |
| `AT,stall` | From idle, increases raw wheel speed by 250 microsteps/s every 120 ms; compares filtered velocity against 70% of expected speed |
| `AT,stop` | Aborts the active routine and restores the saved gain, trim, or speed setting |
| `AT,?` | Prints routine status |

The routine timeout is 45 s. Results remain in RAM until `PS` saves them. Wobble/trim abort if balancing ends or drive input exceeds 0.05.

Stall search runs outside the balance state machine and is not cancelled by `X` or SELECT. Its implemented stop path is `AT,stop`. Radius completion needs a parser fix before it can be used. For now, calibrate radius manually with a measured displacement and `P,WHEELR,value`.

To correct the assumed radius from a known push distance:

$$R_{new}=R_{old}\frac{distance_{actual}}{distance_{reported}}$$

See the [protocol reference](../../firmware/BaseLink/PROTOCOL.md) for complete commands and telemetry fields.

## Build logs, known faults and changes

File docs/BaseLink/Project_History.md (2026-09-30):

# Project History

This records earlier designs and the changes visible in the repository history. Current behavior is described in [System Architecture](System_Architecture.md).

## Timer-driven actuation

The project moved step generation out of the main loop into a 20 kHz hardware timer ISR. Bresenham accumulators distribute STEP pulses for each requested wheel rate. Encoder feedback uses MT6816 A/B signals decoded by ESP32 PCNT hardware.

## IMU estimation and PID control

Earlier firmware used pitch PID control, separate heading/position options, Bluetooth serial tuning, and tab-separated telemetry. The desktop GUI and browser tuner still reflect that interface.

Sensor estimation moved to Mahony quaternion integration and cascaded pitch filtering. The current implementation uses accelerometer/gyro correction; the QMC5883L supplies separate tilt-compensated yaw telemetry.

## ESP-NOW joystick transmitter

`firmware/Controller/Controller.ino` reads an analog joystick and sends a packed forward/steering/enable packet at 50 Hz. An EvoFox bridge sketch was also added in the `feature/evofox_test` work and later removed from the active LQR branch.

The analog transmitter remains in the repository, but current BaseLink does not receive ESP-NOW packets.

## LQR/LQI balancing

The `system/LQR_Controller` work replaced pitch PID with full-state feedback and a position integral. Acceleration is integrated into wheel velocity rather than mapping pitch error directly to speed.

The controller added encoder position hold, velocity tracking, stiff hold, and climb reference tracking. Heading control moved to encoder differential. The branch was merged into `main` and tagged `v2.0.0`.

## Direct Bluetooth gamepad and status ring

Bluepad32 replaced the robot's ESP-NOW input path. The EVOFOX One S pairs directly to the robot, removing the bridge board. NeoPixelBus drives a 16-LED WS2812 ring through RMT for arm, fall, drive, hold, and gesture feedback.

## TMC2226 drivers

TMC2226 replaced TMC2208 through the register-compatible `TMC2209Stepper` class. Separate driver UARTs, address straps, connection tests, and an IFCNT write check made configuration visible at boot.

Historical hardware tests recorded a speed ceiling near 9000 microsteps/s at 1100 mA in both chopper modes. Current compiled defaults are 1500 mA, 1/8 microsteps, StealthChop, StallGuard4 thresholds 76/77, and a common speed cap of 8500 microsteps/s. See [TMC2226 Migration](TMC2226_Migration.md).

## Camera payload and motion I/O

Commit `cbdee62` added camera pan/zoom and torch controls. The left stick drives and steers; the right stick controls the payload. LB became a speed toggle, RB controls the torch, and D-pad buttons select hold modes or adjust brightness.

The shared motor enable moved both drivers onto GPIO 32. Current pan/zoom pins are GPIO 26/0. The wheel-radius and normal-gain update was committed as `e0c6554`.

## Runtime tuning and terrain adaptation

Commit `a8427f0` on `system/control-stack-v3` added:

- A shared 106-parameter store with bounds, metadata, derived conversions, and NVS persistence.
- Live settings for control, driver tuning, IMU, gamepad shaping, ring, and payload.
- Wobble, trim, radius, and stall auto-tune routines.
- Roughness, airborne, and landing detection with pitch-gain softening.
- Explicit START/SELECT events and synchronization after an automatic stop.
- Removal of arming from host `V` enable transitions.
- Terrain fields appended to comma-separated debug telemetry.

Radius completion, stall abort handling, saved driver tuning at boot, and legacy host-tool compatibility remain implementation gaps documented in the [tuning guide](Config_and_Tuning_Guide.md) and [protocol](../../firmware/BaseLink/PROTOCOL.md).

## Separate development branches

ROS workspace, ROS-hosted balancing, SLAM placeholder, and predictive fall-protection experiments exist on separate branches. They are not part of the current BaseLink architecture on `system/control-stack-v3`.

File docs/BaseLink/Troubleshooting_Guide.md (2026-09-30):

# BaseLink Troubleshooting

Use USB serial at **460800 baud**. Start with `P?` and the boot logs. Source references below are in [firmware/BaseLink](../../firmware/BaseLink/).

## No serial data or garbled output

Confirm baud, port, newline handling, and exclusive ownership of the port. The current Radxa console uses 460800 baud and comma-separated protocol records. Check `2pybot-console.service` and `/api/status` for connection state.

The old desktop GUI expects 115200 baud, tab-separated data, and `$` commands, so its parser and controls do not match this firmware.

`radxa_brain.py` also uses 115200 baud. Its baud and wheel-radius conversion must be aligned before its motion gate can use current odometry.

## IMU initialization fails

Check SDA 21, SCL 22, common ground, sensor power, pull-ups, and the ISM6HG256X library. `IMUSensor::begin()` returns false if sensor initialization or accelerometer/gyro configuration fails. The sketch then halts setup.

`QMC5883L init called` is a log message, not a verified compass-detection result.

## Driver reports COMM ERROR

`setupDriver()` tests connection status and an IFCNT increment after one write. Check the driver address straps, PDN_UART routing, and the 1 kOhm TX resistor.

| Driver | UART | RX / TX |
| :--- | :--- | :--- |
| Right | Serial2 | 16 / 17 |
| Left | Serial1 | 18 / 19 |

Both modules use address 0 with MS1/MS2 LOW. Confirm `OK` and 1/8 microstep readback for both. A per-driver error does not halt setup: `StepperControl::begin()` returns true after initialization.

## START or E leaves the robot idle

`motorsRequested` can be set while the robot remains idle. Arming waits for `abs(pitchF) < ARMANG`, default 5 degrees. Check pitch signs and TRIM.

On connection, sticks must pass center calibration before buttons are processed. The first processed button state is adopted, so a held START does not count as a new press. Release it, then press again.

Host `V,...,1` does not arm. Use START or `E`. There is no `STATE_FALLEN`; a fall returns to idle and requires a new request.

## Immediate fall or rapid acceleration

Check sensor, encoder, and motor direction before changing gains:

- Forward tilt: positive `pitchF`.
- Forward tilt rate: positive `rateF`.
- Forward wheel movement: positive controller `velF`.
- Both motor directions: consistent forward travel.

Runtime sign keys are `PITCHSGN`, `RATESGN`, `ENCSGN`, `ACCSGN`, and `GYROSGN`. Motor direction flags remain in `config.h`. Use +1 or -1, not intermediate sign values.

## Oscillation or noisy recovery

Inspect `pitchF`, `rateF`, `satA`, `satV`, and `loopMaxUs`. Check mechanics, motor current, and IMU filter delay before tuning K3/K4. `IMUCUT` defaults to 50 Hz; a lower cutoff adds delay.

Compare with terrain adaptation disabled through `P,TERREN,0`. Wobble tuning reduces K3/K4 while measuring pitch RMS; it is not a full LQR gain redesign. There is no `PID_D_FILTER_ALPHA` setting in current firmware.

## Position drift or unexpected odometry scale

Check encoder counts from both wheels, loaded `WHEELR`, and `ENCSGN`. The compiled radius is 0.050 m. Saved NVS may contain another value. Position feedback comes from encoders, not generated steps.

Normal hold uses K1/K5 and a bounded position integral. Normal driving resets that integral. Near velocity saturation, the hold point moves toward the robot by design.

## Robot turns while trying to hold heading

Heading feedback uses right-minus-left encoder counts. Check encoder wiring/signs, `YAWKP`, `YAWKD`, `YAWMAX`, and differential-rate noise. `YAWRELCH` and `YAWTILT` re-latch heading after large error or tilt.

Compass offsets affect yaw telemetry, not the steering controller. Legacy `$INV_Y` and `$EN_Y` commands are not supported.

## Motors click, skip steps, or overheat

Check supply voltage, mechanical drag, current, and requested wheel rates. `MAXACC` limits common acceleration; `MAXSPD` limits common velocity. Steering can increase one wheel's rate beyond the common rate.

Use `P,CURRENT,value` to update both the parameter store and hardware. `M=value` only writes hardware. The current parameter bounds are 300 through 2000 mA; the actual motor rating still determines the usable value.

## Saved driver tuning does not return after reset

Boot uses `P.motorMa`, but StallGuard/CoolStep setup still reads compiled defaults. The first parameter hardware callback is skipped. After driver initialization, `PL` applies the saved driver values.

`CSSEMIN=0` disables CoolStep at runtime. Optional DIAG reporting requires GPIO 34/35 wiring and `USE_DIAG_PINS=1`. DIAG events are report-only and do not stop balancing.

## Gamepad input has no effect

Check connection/calibration logs and `RADXATMO`. A host that continues sending `V` commands owns drive priority even if both requested axes are zero. Stop the host's transmission and wait for freshness to expire.

Axis direction uses `PADFWD` and `PADSTR`. The active deadzone key is `STICKDZ`; `PADDZ` does not affect the radial mapping. Keep `STICKDZ > 0` and `SNAPOUT > SNAPIN` to avoid zero denominators.

## Camera travel or torch setting looks wrong

Pan/zoom pins are **26/0**, as defined in `config.h`; older source comments mention other pins. Requested servo positions can exceed 180 degrees, but `_servoWriteDeg()` clamps physical output to 180.

`SVIDLE` can stop servo pulses after inactivity. `SVRATE` is the software write rate, not the PWM frequency. `TRCHBOOT` does not initialize `_torchPct` in current code, and its boot print uses an incorrect integer format for a floating-point field. Inspect torch state through `S` or an explicit `B=value` command.

## Auto-tune will not finish or stop

- Radius: the busy check intercepts `AT,done`; use manual radius calibration until the parser is corrected.
- Stall: the routine controls motors while the balance state is idle. `X` and SELECT do not abort it; use `AT,stop`.
- Wobble/trim: leaving balancing or moving the drive input beyond 0.05 aborts the routine.
- Completion does not save NVS. Use `PS` only after reviewing values.

## Debug stream is too frequent

`DEBUG_STREAM` starts true. `DEBUG_PERIOD_MS=10` requests a nominal 100 Hz, not the older 10 Hz comment. Send `L` to toggle it. Odometry remains at 50 Hz. Logs are event-driven and are not disabled by `L`.

For more source-level checks, see [the detailed reference](100+_WHAT_AND_HOWS.md).

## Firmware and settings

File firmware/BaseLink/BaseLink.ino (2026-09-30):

/*
 * ============================================================
 *  BaseLink_LQR.ino — 2PyBot firmware, Package B (LQR / LQI)

                            LATESTT
 * ============================================================
 *  Control law: optimal full-state feedback on the linearized
 *  velocity-driven inverted pendulum, augmented with a position
 *  integral (LQI) that nulls drift from the unknown CoG offset.
 *  =]`1
 *      u = -( K1*(x-xRef) + K2*v + K3*pitch + K4*pitchRate + K5*z )
 *      z = Integral(x - xRef),   u = wheel acceleration
 *      vCmd += u*dt  ->  stepper ISR (steps/s)
 *
 *  Gains were computed offline by solving the continuous-time 
 *  algebraic Riccati equation (see tools/simulate_controllers.py,
 *  which also regenerates them for different geometry). Validated
 *  in simulation: 0.5 cm RMS station keeping under a 0.35 deg CoG
 *  error, 2.3 deg peak excursion for a 45 deg/s shove, < 0.3 cm
 *  steady-state error on a 0.5 m position command.
 *
 *  Radxa serial bridge (USB serial, 115200):
 *    OUT 50 Hz :  O,<millis>,<encL>,<encR>,<pitchDeg>,<yawDeg>\n
 *    IN        :  V,<forward -1..1>,<steering -1..1>,<enable 0|1>\n
 *
 *  Tuner commands (same serial port, newline terminated):
 *    E enable    X e-stop    C cal gyro    S settings
 *    L toggle debug stream   R reset controller   ? help
 *    K1=..K5=<v> LQR gains   T=<v> pitch trim (deg)   M=<mA> current
 *
 *  EVOFOX One S pairs DIRECTLY over Bluetooth (Bluepad32 board
 *  core; ESP-NOW removed so BT owns the radio). The Radxa keeps
 *  override authority while its 'V' lines are fresh -- the
 *  vision guard works unchanged.
 * ============================================================
 */

#include "config.h"
#include "params.h"
#include "autotune.h"
#include "terrain.h"
#include "imu_sensor.h"
#include "stepper_control.h"
#include "bt_gamepad.h"    // EVOFOX One S DIRECT Bluetooth (replaces espnow_comm.h)
#include "led_ring.h"      // WS2812 16-LED expression ring on GPIO 15
#include "payload.h"       // 2x MG90S servo (GPIO 0/12) + torch MOSFET (GPIO 2)

IMUSensor imu;

// ============================================================
//  STATE
// ============================================================
enum RobotState { STATE_IDLE, STATE_BALANCING };
RobotState state       = STATE_IDLE;
bool motorsRequested   = false;
bool DEBUG_STREAM      = true;
bool RADXA_STREAM      = true;

// Forward-positive measurements (see config.h sign conventions)
float pitchF = 0.0f, rateF = 0.0f;      // deg, deg/s
float posM   = 0.0f, velF  = 0.0f;      // m, m/s (encoder-based)
int64_t encRawL = 0, encRawR = 0;       // raw signed counts (for O-stream)
float encDiff = 0.0f, diffRateF = 0.0f; // (R - L) counts, fwd-signed

// Controller state
float vCmd = 0.0f;          // integrated velocity command (m/s)
float zInt = 0.0f;          // LQI position integral (m*s)
float xRef = 0.0f;          // position hold target (m)
float uOut = 0.0f;          // last acceleration command (m/s^2)
float steerSteps = 0.0f;    // current differential (steps/s)
float diffTarget = 0.0f;    // heading-hold encoder diff target

// ---- telemetry instrumentation (read-only, no control effect) ----
uint8_t  satV = 0, satA = 0;     // clamp hit this cycle: velocity cap / accel limit
uint32_t loopMaxUs = 0;          // worst loop period since last D line

// ---- expression features (gamepad) ----
bool  stiffHold = false;    // "H,1": high-stiffness hold gain set
bool  climbMode = false;    // "H,2" / D-pad DOWN: slope LQI mode
float lookCmd   = 0.0f;     // "A,x": sustained yaw offset, -1..1

// Gesture engine: keyframes of (duration, fwd, steer) fed into the
// normal drive inputs. Balancer + safety limits stay in charge.
struct GStep { uint16_t ms; float fwd; float steer; };
static const GStep GEST_YES[]   = {{350,0.50f,0},{350,-0.50f,0},{350,0.50f,0},{350,-0.50f,0},{200,0,0}};
static const GStep GEST_NO[]    = {{250,0,0.50f},{250,0,-0.50f},{250,0,0.50f},{250,0,-0.50f},{250,0,0.50f},{250,0,-0.50f},{150,0,0}};
static const GStep GEST_SPIN[]  = {{2400,0,0.55f},{250,0,0}};
static const GStep GEST_DANCE[] = {{300,0.50f,0},{300,-0.50f,0},{500,0,0.60f},{500,0,-0.60f},
                                   {300,0.50f,0},{300,-0.50f,0},{1200,0,0.55f},{1200,0,-0.55f},
                                   {300,-0.50f,0},{300,0.50f,0},{250,0,0}};
const GStep* gestSeq = nullptr;
uint8_t  gestLen = 0, gestIdx = 0;
uint32_t gestStepStart = 0;

// Gains and trim live in the parameter store (params.h) so the GUI, the app
// and the legacy K1=/T= serial tuners all write the SAME memory. These
// aliases keep the controller code below reading exactly as it always did.
// (Without them the sliders write P.* while the loop reads a private copy --
//  the tuning appears to do nothing at all.)
#define k1        P.k1
#define k2        P.k2
#define k3        P.k3
#define k4        P.k4
#define k5        P.k5
#define pitchTrim P.pitchTrim

// Drive inputs after link arbitration
float cmdFwd = 0.0f, cmdSteer = 0.0f;

// Radxa link
uint32_t radxaLastRx = 0;
float    radxaFwd = 0.0f, radxaSteer = 0.0f;
uint8_t  radxaEn = 0, radxaEnPrev = 0;


// Serial line buffer
char  rxBuf[96];
uint8_t rxLen = 0;

// Timing
unsigned long lastLoopUs = 0;
uint32_t lastOdomMs = 0, lastDbgMs = 0, lastBlinkMs = 0;
bool ledState = false;

// ============================================================
//  Hooks the auto-tune routines need from the sketch
// ============================================================
bool at_isBalancing() { return state == STATE_BALANCING; }
void at_motorsOff()   { steppers.setSpeeds(0, 0); steppers.disable(); }
void at_setWheelSpeed(float stepsPerSec) {
    // Raw drive, used only by the stall search with the wheels off the ground.
    if (!steppers.isEnabled()) steppers.enable();
    int32_t v = (int32_t)stepsPerSec;
    steppers.setSpeeds(v, v);
}

// ============================================================
//  params_applyHardware() — called by params.h on every write.
//  Keeps hardware in step with the parameter store. Anything that
//  is read fresh each loop (gains, limits, deadbands) needs nothing
//  here; only latched hardware settings do.
// ============================================================
void params_applyHardware(bool currentChanged) {
    static bool ready = false;          // ignore calls before begin()
    if (!ready) { ready = true; return; }
    imu.setFilterCutoff(P.imuCutoff);
    steppers.applyTuning();                 // SGTHRS / TCOOLTHRS / CoolStep
    if (currentChanged) steppers.setCurrent((uint16_t)P.motorMa);
}

// ============================================================
//  HELPERS
// ============================================================
static inline float clampf(float v, float lo, float hi) {
    return v < lo ? lo : (v > hi ? hi : v);
}

void resetController() {
    vCmd = 0.0f; zInt = 0.0f; uOut = 0.0f;
    xRef = posM;
    steerSteps = 0.0f; diffTarget = encDiff;
    gestSeq = nullptr; stiffHold = false; climbMode = false; lookCmd = 0.0f;
}

void startGesture(const GStep* seq, uint8_t len, const char* name) {
    if (state != STATE_BALANCING) { Serial.println("[GEST] Not balancing -- ignored"); return; }
    if (climbMode) { Serial.println("[GEST] Climb mode -- gestures ignored"); return; }
    gestSeq = seq; gestLen = len; gestIdx = 0; gestStepStart = millis();
    Serial.printf("[GEST] %s\n", name);
}
void stopGesture() { gestSeq = nullptr; }

void requestEnable() {
    motorsRequested = true;
    Serial.println("[MAIN] Enable requested — will arm when upright");
}

void requestDisable(const char* why) {
    motorsRequested = false;
    // Push the state back into the pad module. Without this, an AUTOMATIC
    // disable (FELL / RATE SPIKE) left the pad still believing it was armed,
    // so the next START press produced no edge and appeared to do nothing.
    btgamepad_syncArmed(false);
    if (state == STATE_BALANCING) {
        steppers.setSpeed(0);
        steppers.disable();
        state = STATE_IDLE;
    }
    Serial.printf("[MAIN] Motors OFF (%s)\n", why);
}

// ============================================================
//  SERIAL PARSER — Radxa 'V' lines + tuner commands, one reader
// ============================================================
void handleLine(char* line) {
    // P-commands (parameter get/set/save) are handled first.
    if (at_handleLine(line)) return;      // AT,<routine>
    if (params_handleLine(line)) return;

    if (line[0] == 'V' && line[1] == ',') {
        float f = 0, s = 0; int en = 0;
        if (sscanf(line + 2, "%f,%f,%d", &f, &s, &en) == 3) {
            radxaFwd   = clampf(f, -1.0f, 1.0f);
            radxaSteer = clampf(s, -1.0f, 1.0f);
            radxaEn    = en ? 1 : 0;
            radxaLastRx = millis();
            // A remote link may always STOP the robot; it may never START it.
            // Arming stays a deliberate local action (pad START, or 'E' on
            // USB serial). Without this, the Cubie's very first V-line --
            // including the vision guard's own "V,0,0,1" -- armed the robot.
            if (!radxaEn && radxaEnPrev)  requestDisable("Radxa disable");
            radxaEnPrev = radxaEn;
        }
        return;
    }

    // ---- expression commands (from the phone app / Radxa) ----
    if ((line[0] == 'G' || line[0] == 'g') && line[1] == ',') {
        const char* n = line + 2;
        if      (!strncmp(n, "yes",   3)) startGesture(GEST_YES,   sizeof(GEST_YES)/sizeof(GStep),   "nod YES");
        else if (!strncmp(n, "no",    2)) startGesture(GEST_NO,    sizeof(GEST_NO)/sizeof(GStep),    "nod NO");
        else if (!strncmp(n, "spin",  4)) startGesture(GEST_SPIN,  sizeof(GEST_SPIN)/sizeof(GStep),  "spin");
        else if (!strncmp(n, "dance", 5)) startGesture(GEST_DANCE, sizeof(GEST_DANCE)/sizeof(GStep), "dance");
        else if (!strncmp(n, "stop",  4)) { stopGesture(); Serial.println("[GEST] stop"); }
        else Serial.printf("[GEST] Unknown: %s\n", n);
        return;
    }
    if ((line[0] == 'H' || line[0] == 'h') && line[1] == ',') {
        int hv = atoi(line + 2);
        if (hv == 2) {                                  // CLIMB mode
            climbMode = true; stiffHold = false; stopGesture();
            xRef = posM;
            Serial.println("[HOLD] CLIMB");
        } else {
            climbMode = false;
            zInt = clampf(zInt, -P.zIntLim, P.zIntLim); // re-shrink climb integral
            stiffHold = hv != 0;
            if (stiffHold) { xRef = posM; zInt = 0.0f; }   // hold RIGHT HERE
            Serial.printf("[HOLD] %s\n", stiffHold ? "STIFF" : "normal");
        }
        return;
    }
    if ((line[0] == 'A' || line[0] == 'a') && line[1] == ',') {
        lookCmd = clampf(atof(line + 2), -1.0f, 1.0f);
        return;
    }

    // ---- tuner ----
    char cmd = toupper(line[0]);
    char* eq = strchr(line, '=');
    float val = eq ? atof(eq + 1) : 0.0f;

    if (eq) {
        if      (cmd == 'K' && line[1] == '1') { k1 = val; Serial.printf("[TUNE] K1 = %.4f\n", val); }
        else if (cmd == 'K' && line[1] == '2') { k2 = val; Serial.printf("[TUNE] K2 = %.4f\n", val); }
        else if (cmd == 'K' && line[1] == '3') { k3 = val; Serial.printf("[TUNE] K3 = %.4f\n", val); }
        else if (cmd == 'K' && line[1] == '4') { k4 = val; Serial.printf("[TUNE] K4 = %.4f\n", val); }
        else if (cmd == 'K' && line[1] == '5') { k5 = val; Serial.printf("[TUNE] K5 = %.4f\n", val); }
        else if (cmd == 'T') { pitchTrim = val; Serial.printf("[TUNE] Trim = %.3f deg\n", val); }
        else if (cmd == 'M') { steppers.setCurrent((uint16_t)val); }
        else if (cmd == 'B') { payload_torchSetPct((int)val); }
        else if (cmd == 'P') { payload_setYaw(val);  Serial.printf("[PAY] Pan  -> %.0f deg\n", payload_yaw());  }
        else if (cmd == 'Z') { payload_setZoom(val); Serial.printf("[PAY] Zoom -> %.0f deg\n", payload_zoom()); }
        else Serial.printf("[TUNE] Unknown: %s\n", line);
        return;
    }
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
void loop() {
    unsigned long nowUs = micros();
    unsigned long elapsed = nowUs - lastLoopUs;
    if (elapsed < LOOP_PERIOD_US) return;
    lastLoopUs = nowUs;
    if (elapsed > loopMaxUs) loopMaxUs = elapsed;
    float dt = elapsed / 1000000.0f;
    if (dt > 0.05f) dt = 0.05f;               // guard after stalls

    // ---- 1. sensors ----
    imu.update(dt);
    pitchF = P.pitchSign * (imu.getPitch() - pitchTrim);
    // road-condition estimate: |accel| deviation from 1 g + rate spikes
    terrain_update(sqrtf(imu.getAx()*imu.getAx() + imu.getAy()*imu.getAy() +
                         imu.getAz()*imu.getAz()), rateF, dt);
    rateF  = P.rateSign  *  imu.getPitchRate();

    encRawL = steppers.getPositionL();
    encRawR = steppers.getPositionR();
    float posL = P.encSign * (float)encRawL;
    float posR = P.encSign * (float)encRawR;

    static float posPrev = 0.0f; static bool posInit = false;
    posM = 0.5f * (posL + posR) / P.countsPerM;
    if (!posInit) { posPrev = posM; posInit = true; }
    float vRaw = (posM - posPrev) / dt;
    posPrev = posM;
    const float aV = 1.0f - expf(-2.0f * PI * 15.0f / LOOP_FREQ_HZ);  // 15 Hz EMA
    velF += aV * (vRaw - velF);

    static float diffPrev = 0.0f; static bool diffInit = false;
    encDiff = posR - posL;
    if (!diffInit) { diffPrev = encDiff; diffInit = true; }
    float dRaw = (encDiff - diffPrev) / dt;
    diffPrev = encDiff;
    diffRateF += aV * (dRaw - diffRateF);

    // ---- 2. inputs ----
    pollSerial();
    btgamepad_update();   // fills joyForward/joySteering/joyEnable (same names as before)

    // Gamepad expression buttons -> existing gesture engine (edge-detected in bt_gamepad.h)
    switch (btgamepad_takeGesture()) {
        case 1: startGesture(GEST_YES,   sizeof(GEST_YES)/sizeof(GStep),   "nod YES"); break;
        case 2: startGesture(GEST_NO,    sizeof(GEST_NO)/sizeof(GStep),    "nod NO");  break;
        case 3: startGesture(GEST_SPIN,  sizeof(GEST_SPIN)/sizeof(GStep),  "spin");    break;
        case 4: startGesture(GEST_DANCE, sizeof(GEST_DANCE)/sizeof(GStep), "dance");   break;
        case 5: stiffHold = !stiffHold;
                if (stiffHold) { climbMode = false; xRef = posM; zInt = 0.0f; }
                Serial.printf("[HOLD] %s (pad)\n", stiffHold ? "STIFF" : "normal");
                break;
        case 6: climbMode = !climbMode;
                if (climbMode) { stiffHold = false; stopGesture(); xRef = posM; }
                else           { zInt = clampf(zInt, -P.zIntLim, P.zIntLim); }
                Serial.printf("[HOLD] %s (pad)\n", climbMode ? "CLIMB" : "climb off");
                break;
        default: break;
    }

    // ---- 2b. camera payload: right stick pans/zooms, RB torch,
    //          D-pad LEFT/RIGHT dims. Deliberately OUTSIDE the state
    //          machine: the camera and light stay usable whether the
    //          robot is balancing, idle, or lying on its side.
    if (btgamepad_takeTorchToggle()) payload_torchToggle();
    {
        int8_t tStep = btgamepad_takeTorchStep();
        if (tStep) payload_torchStep(tStep);
    }
    payload_update(dt, joyPanX, joyZoomY);

#if USE_DIAG_PINS
    // TMC2226 DIAG stall flags: report only, never auto-act — a false
    // trip during an aggressive balance recovery must not cut motors.
    {
        static uint32_t stallSeenL = 0, stallSeenR = 0, stallMuteMs = 0;
        uint32_t sl = steppers.stallCountL(), sr = steppers.stallCountR();
        if ((sl != stallSeenL || sr != stallSeenR) && millis() - stallMuteMs > 250) {
            Serial.printf("[STALL] wheel stall flags  L=%lu  R=%lu\n",
                          (unsigned long)sl, (unsigned long)sr);
            stallSeenL = sl; stallSeenR = sr; stallMuteMs = millis();
        }
    }
#endif

    // Speed-mode edge -> ring cue (blue dash = HIGH, green settle = LOW)
    static uint8_t spdPrev = SPEED_BOOT_HIGH;
    if (joySpeedHigh != spdPrev) {
        spdPrev = joySpeedHigh;
        leds_event(spdPrev ? LED_EV_SPEED_HI : LED_EV_SPEED_LO);
    }

    // Gamepad enable edge (works even when Radxa has drive authority)
    // Enable/disable on real button PRESSES, not on level transitions.
    // joyEnable boots at 0, so the old "falling edge" test could never fire
    // before START had been pressed once -- SELECT was a no-op from boot.
    int8_t enEv = btgamepad_takeEnableEvent();
    if (enEv > 0) requestEnable();
    if (enEv < 0) requestDisable("joystick e-stop");

    // Drive-authority arbitration: Radxa fresh > joystick fresh > zero
    bool radxaFresh = (millis() - radxaLastRx) < P.radxaTmo && radxaLastRx != 0;
    bool joyFresh   = (millis() - lastJoyPacketMs) < P.joyTmo && lastJoyPacketMs != 0;
    if (radxaFresh) {
        cmdFwd = radxaFwd;  cmdSteer = radxaSteer;
    } else if (joyFresh) {
        // Dual speed mode (LB = LOW, RB = HIGH): scales the pad's authority
        // INSIDE the existing caps. Full stick in LOW mode commands
        // P.spdLoDrv * P.maxDriveV and
        // P.spdLoStr * P.maxSteerSt. Radxa override (above)
        // and gesture keyframes (below) stay full-scale on purpose, and
        // the balancer's own limits (P.vMax / P.aMax) never shrink.
        float sD = joySpeedHigh ? 1.0f : P.spdLoDrv;
        float sS = joySpeedHigh ? 1.0f : P.spdLoStr;
        cmdFwd   = clampf(joyForward * P.joyFwdSc,  -1.0f, 1.0f) * sD;
        cmdSteer = clampf(joySteering * P.joyStrSc, -1.0f, 1.0f) * sS;
    } else {
        cmdFwd = 0.0f; cmdSteer = 0.0f;
    }

    // ---- 2b. gesture playback (operator input always overrides) ----
    if (gestSeq) {
        if (fabsf(cmdFwd) > 0.10f || fabsf(cmdSteer) > 0.20f) {
            stopGesture();                        // human grabbed the stick
        } else {
            if (millis() - gestStepStart >= gestSeq[gestIdx].ms) {
                gestIdx++; gestStepStart = millis();
                if (gestIdx >= gestLen) stopGesture();
            }
            if (gestSeq) { cmdFwd = gestSeq[gestIdx].fwd; cmdSteer = gestSeq[gestIdx].steer; }
        }
    }

    // ---- 3. state machine ----
    if (state == STATE_IDLE) {
        if (motorsRequested && fabsf(pitchF) < P.armAngle) {
            resetController();
            steppers.enable();
            state = STATE_BALANCING;
            leds_event(LED_EV_ARM);
            Serial.println("[MAIN] -> BALANCING");
        }
    } else { // BALANCING
        if (fabsf(pitchF) > P.maxTilt || fabsf(rateF) > P.maxRate) {
            leds_event(LED_EV_FALL);
            requestDisable(fabsf(pitchF) > P.maxTilt ? "FELL" : "RATE SPIKE");
        } else {
            runController(dt);
        }
    }

    at_update(dt);          // auto-tune state machine (no-op when idle)

    // ---- 3b. expression ring (rate-limited internally, non-blocking) ----
    {
        LedInputs li;
        li.balancing    = (state == STATE_BALANCING);
        li.armRequested = motorsRequested;
        li.fwd          = cmdFwd;
        li.steer        = cmdSteer;
        li.velF         = velF;
        li.pitchF       = pitchF;
        li.ex           = posM - xRef;
        li.stiffHold    = stiffHold;
        li.climbMode    = climbMode;
        li.gestActive   = (gestSeq != nullptr);
        li.radxaFresh   = radxaFresh;
        li.padConnected = btgamepad_connected();
        leds_update(li);
    }

    // ---- 4. odometry stream to Radxa, 50 Hz, always on ----
    uint32_t nowMs = millis();
    if (nowMs - lastOdomMs >= ODOM_PERIOD_MS && RADXA_STREAM) {
        lastOdomMs = nowMs;
        Serial.printf("O,%lu,%lld,%lld,%.2f,%.2f\n",
                      (unsigned long)nowMs,
                      (long long)encRawL, (long long)encRawR,
                      imu.getPitch(), imu.getYaw());
    }

    // ---- 5. optional human-readable debug, 10 Hz ----
     if (DEBUG_STREAM && nowMs - lastDbgMs >= DEBUG_PERIOD_MS) {
        lastDbgMs = nowMs;
        // D,ms,pF,w,u,v,ex,vCmdSteps,steerSteps,satV,satA,loopMaxUs,speedHi,state,fwd,str
        Serial.printf("D,%lu,%.2f,%.1f,%.2f,%.3f,%.3f,%.0f,%.0f,%u,%u,%lu,%u,%u,%.2f,%.2f,"
                      "%.3f,%.3f,%.2f,%u,%lu\n",
                      (unsigned long)nowMs, pitchF, rateF, uOut, velF, posM - xRef,
                      vCmd * P.stepsPerM, steerSteps, satV, satA,
                      (unsigned long)loopMaxUs, (unsigned)joySpeedHigh,
                      (unsigned)(state == STATE_BALANCING), cmdFwd, cmdSteer,
                      TERR.accelMag, TERR.rough, TERR.soften,
                      (unsigned)TERR.state, (unsigned long)TERR.drops);
        loopMaxUs = 0;
    }
}

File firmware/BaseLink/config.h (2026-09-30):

/*
 * ============================================================
 *  config.h — 2PyBot BaseLink (Package B: LQR / LQI)
 * ============================================================
 *  Pins, hardware parameters and control gains in one place.
 *
 *  WHAT CHANGED vs the old firmware
 *  --------------------------------
 *  The old balance law mapped angle error DIRECTLY to wheel
 *  velocity. For a velocity-actuated (stepper) pendulum that
 *  system always keeps one unstable pole (~ +1.6 rad/s) — it
 *  can never stand still, which is exactly the drift you saw.
 *
 *  New structure (proven in simulation, see REPORT.md):
 *      LQR full-state feedback with position-integral augmentation
 *      u = -( K1*(x-xRef) + K2*v + K3*pitch + K4*pitchRate + K5*z )
 *      z = Integral(x - xRef);  u = wheel acceleration, integrated
 *      into the ISR velocity command.
 *  The gains below were computed offline by solving the continuous
 *  algebraic Riccati equation for the linearized velocity-driven
 *  pendulum (tools/simulate_controllers.py regenerates them). The
 *  integral state absorbs the unknown CoG offset -> zero drift.
 * ============================================================
 */

#ifndef CONFIG_H
#define CONFIG_H

// ============================================================
//  PIN DEFINITIONS — ESP32 38-Pin DevKit  (unchanged)
// ============================================================

// ---- Right Stepper Motor (TMC2226) ----
#define RIGHT_STEP_PIN    33
#define RIGHT_DIR_PIN     25
#define MOTOR_EN_PIN      32   // shared: BOTH drivers' EN wired here
#define RIGHT_UART_TX     17    // 1 kOhm inline resistor on TX line.
#define RIGHT_UART_RX     16

// ---- Left Stepper Motor (TMC2226) ----
#define LEFT_STEP_PIN     27
#define LEFT_DIR_PIN      14
// LEFT_EN_PIN removed — the left driver's EN now joins MOTOR_EN_PIN (32).
// enable()/disable() always drove both pins to the same level, so the
// second GPIO bought nothing. GPIO 26 is now free.
#define LEFT_UART_TX      19    // 1 kOhm inline resistor on TX line.
#define LEFT_UART_RX      18

// ---- I2C Bus ----
#define I2C_SDA           21
#define I2C_SCL           22
#define I2C_CLOCK_HZ      400000
// #define ONBOARD_LED    2   <-- REPURPOSED as TORCH_PIN (camera payload).
//                              Deliberately left undefined: the WS2812 ring
//                              replaced this status LED, and if any old code
//                              still digitalWrite()s pin 2 it would fight the
//                              torch PWM. Commenting it out turns that into a
//                              compile error instead of a flickering light.

// ---- MT6816 ABZ Quadrature Encoders (PCNT hardware decode) ----
#define ENC_LEFT_A         4
#define ENC_LEFT_B         5
#define ENC_RIGHT_A       13
#define ENC_RIGHT_B       23
#define ENCODER_PPR       1024
#define ENCODER_CPR       (ENCODER_PPR * 4)   // 4096 counts/rev
#define PCNT_H_LIM        30000
#define PCNT_L_LIM       -30000

// ============================================================
//  MOTOR / DRIVER PARAMETERS  (unchanged)
// ============================================================
// TMC2226 (TMC2209 register set). UART VERIFIED WORKING on both
// drivers (IFCNT write-check, test sketch) — values below actually
// reach the chips now. Microstepping is programmed OVER UART to 1/8,
// same as the old strapping, so STEPS_PER_M and every tuned gain stay
// valid. NOTE: on the 2226 the MS1/MS2 pins double as the UART
// ADDRESS — both LOW = 1/8 standalone AND address 0, so the wiring
// is already consistent. Verify after flashing: while moving gently,
// debug 'v' must equal vCmd/STEPS_PER_M.
#define MICROSTEPS           8
#define DRV_UART_ADDR        0b00    // MS1/MS2 low on both modules
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

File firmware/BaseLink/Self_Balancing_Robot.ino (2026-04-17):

/*
 * ============================================================
 *  Self_Balancing_Robot.ino
 * ============================================================
 *  Phase 1 — Core Self-Balancing and Locomotion Physics
 *
 *  Hardware Configuration:
 *    - ESP32 Development Board (38-pin definition).
 *    - Dual NEMA17 Stepper Motors driven securely by TMC2208 
 *      hardware operating via discrete UART manipulation.
 *    - ISM6HG256X high-precision IMU interacting over I2C.
 *
 *  Control Loop Execution (Precisely 200 Hz):
 *    1. Interrogates IMU strictly → fuses raw vectors via Mahony AHRS 
 *       → extracts discrete pitch and yaw Euler metrics.
 *    2. Dual PID controllers actively assess algorithmic setpoints 
 *       → resolves reactive motor speed commands.
 *    3. Asynchronous hardware timer ISR generates discrete 
 *       step pulses flawlessly decoupled from the mainline 
 *       processing loop.
 *
 *  Available Serial Command Interfaces:
 *    P=15  I=0  D=0.8  T=0  — Modify PID configurations live without code reflashing.
 *    E / X                  — Assert enable / trigger emergency motor disconnect.
 *    S                      — Render persistent algorithmic settings.
 *    ?                      — Render command syntax help documentation.
 *
 *  Author: Atharva
 *  Date:   April 2026
 * ============================================================
 */

#include "config.h"
#include "pid_controller.h"
#include "imu_sensor.h"
#include "stepper_control.h"
#include "serial_tuner.h"
#include "espnow_comm.h"
#include <BluetoothSerial.h>

// ============================================================
//  GLOBAL ABSTRACTION OBJECTS
// ============================================================

// Instantiates the primary inertial mathematical fusion construct.
IMUSensor imu;

// Constructs the primary PID structure rigidly governing fundamental gravity balancing.
PIDController pid(
    DEFAULT_KP, DEFAULT_KI, DEFAULT_KD,
    DEFAULT_TARGET_ANGLE,
    PID_OUTPUT_MIN, PID_OUTPUT_MAX,
    INTEGRAL_LIMIT,
    true, ADAPTIVE_ERROR_THRESHOLD, ADAPTIVE_KP_BOOST,
    PID_D_FILTER_ALPHA
);

// Constructs a supplementary PID strictly managing rotational velocity (Heading Hold).
PIDController yawPid(
    YAW_KP, YAW_KI, YAW_KD,
    0.0f,
    -MAX_STEERING, MAX_STEERING,
    1000.0f
);

// Instantiates the core Bluetooth stack providing wireless serial telemetry output.
BluetoothSerial SerialBT;

// ============================================================
//  PHYSICS ENGINE STATE VARIABLES
// ============================================================

// Target modifiers driving physical translation relative to absolute setpoint.
float targetAngleOffset = 0.0f;
float targetYaw = 0.0f;
float steeringOffset = 0.0f;
float targetSteering = 0.0f;

// Operational control paradigms defining autonomous inputs.
char driveState = 'X'; // Logical driving state tracking.
int32_t latestLeftSpeed = 0;
int32_t latestRightSpeed = 0;

// Logical toggles modifying secondary calculus parameters dynamically.
bool invertYaw = true; // Flips fundamental PID evaluation parity.
bool enableDriftCorrection = true; // Actuates the algorithmic Odometry position hold constraint.
bool enableYawPID = false; // Toggles strictly between manual yaw mapping vs active PID control.

// Primary constants influencing manual user driving capability logic.
float dynamicTargetAngle = DEFAULT_TARGET_ANGLE;
float manualDriveTilt = 3.0f;

// Variable tracking structural displacement actively during position-hold procedures.
bool DEBUG = true; // Toggles high-frequency serial evaluation rendering via UART.
float posHoldKp = POS_HOLD_KP;
float posHoldKd = POS_HOLD_KD;
float maxPosHoldTilt = MAX_POS_HOLD_TILT;
int32_t heldPosition = 0;
int32_t lastPosition = 0;

// Instantiates the live parsing engine consuming Serial updates actively.
SerialTuner tuner(pid, steppers, imu);

// ============================================================
//  EXECUTION TIMING METRICS
// ============================================================
unsigned long lastLoopUs   = 0;
unsigned long loopCounter  = 0;
unsigned long lastPrintMs  = 0;
unsigned long lastBlinkMs  = 0;
bool onboardLedState       = false;

// ============================================================
//  STATE MACHINE DEFINITIONS
// ============================================================
// Represents the strict chronological state sequence prohibiting 
// unpredictable mechanical execution states.
enum RobotState {
    STATE_INIT,        // Hardware bootstrapping and mathematical zeroing.
    STATE_IDLE,        // Safe state, motors disabled physically, pending user input.
    STATE_BALANCING,   // Active physics evaluation running in closed loops.
    STATE_FALLEN       // Catastrophic error state disabling hardware following a violation.
};

RobotState state = STATE_INIT;
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

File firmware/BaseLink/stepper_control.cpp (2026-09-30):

/*
 * ============================================================
 *  stepper_control.cpp — Dual TMC2226 implementation
 * ============================================================
 *  Implements high-frequency hardware timer ISR step generation
 *  and asynchronous UART configuration for both stepper motors.
 *
 *  Odometry sourced from MT6816 magnetic encoders via PCNT
 *  hardware quadrature decoding. Step counting is not used.
 * ============================================================
 */

#include "stepper_control.h"
#include "soc/gpio_struct.h"

// ============================================================
//  Global instance & ISR trampoline
// ============================================================
StepperControl steppers;

// Mutex preventing data corruption if the ISR fires while the
// main loop is writing to the shared volatile speed variables.
portMUX_TYPE timerMux = portMUX_INITIALIZER_UNLOCKED;

// The hardware timer requires a plain C function pointer.
// This trampoline forwards the interrupt into the C++ class.
void IRAM_ATTR stepperTimerISR() {
    steppers.tick();
}

// ============================================================
//  Static PCNT overflow accumulators
// ============================================================
volatile int64_t StepperControl::_encOverflowL = 0;
volatile int64_t StepperControl::_encOverflowR = 0;

#if USE_DIAG_PINS
volatile uint32_t StepperControl::_stallL = 0;
volatile uint32_t StepperControl::_stallR = 0;
static void IRAM_ATTR diagIsrL() { StepperControl::_stallL++; }
static void IRAM_ATTR diagIsrR() { StepperControl::_stallR++; }
#endif

// ============================================================
//  PCNT overflow ISR — extends 16-bit counters to 64-bit
// ============================================================
// Fires when the PCNT hardware counter hits ±PCNT_H/L_LIM.
// Accumulates the overflow into 64-bit software trackers.
static void IRAM_ATTR pcnt_overflow_isr(void *arg) {
    pcnt_unit_t unit = (pcnt_unit_t)(intptr_t)arg;
    uint32_t status = 0;
    pcnt_get_event_status(unit, &status);
    volatile int64_t& acc = (unit == PCNT_UNIT_0) ? StepperControl::_encOverflowL
                                                   : StepperControl::_encOverflowR;
    if (status & PCNT_EVT_H_LIM) acc += PCNT_H_LIM;
    if (status & PCNT_EVT_L_LIM) acc += PCNT_L_LIM;
}
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

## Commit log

2026-04-17 chore: add assets/ folder and .gitkeep for empty directories
    - Track hardware/, software/, models/ with .gitkeep so they appear on GitHub
    - Add assets/ folder for demo videos, build photos, and screenshots
    - Update README with assets/ in project tree and Media section
2026-04-18 Revise IMU model and expand component list in README
    Updated IMU model and added additional components for clarity.
2026-04-18 fix: remove square brackets from Mermaid edge labels in Controller arch diagram
2026-04-18 fix(ci): use arduino-cli directly for mismatched .ino names, suppress E701 lint rule
2026-04-18 fix(ci): fix E701 lint errors, use arduino-cli directly, trigger all workflows
    [config.h, robot_controller_ui.py]
2026-04-18 refactor: rename firmware sketches and fix CI workflow paths
    - Rename Self_Balancing_Robot.ino -> BaseLink.ino (firmware/BaseLink/)
    - Rename Joystick_Transmitter.ino -> Controller.ino (firmware/Controller/)
    - Fix firmware-ci.yml: update both arduino-cli compile paths to match new filenames
    - Fix firmware-ci.yml: remove stale comment about filename/directory mismatch
    - Update README.md: directory tree, firmware modules table, Getting Started steps
    - Update docs/BaseLink/Program_Flow_State_Machine.md: filename reference in intro
    - Update firmware/BaseLink/system_architecture.md: Mermaid diagram node label and section heading
    - Update firmware/Controller/Controller.ino: header comment filename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
    [BaseLink.ino, Controller.ino, robot_controller_ui.py]
2026-04-18 ci: fix BaseLink partition, add release workflow, fix ruff formatter
    - firmware-ci.yml: switch BaseLink FQBN to PartitionScheme=huge_app (3MB)
    resolves 'text section exceeds available space' build failure (sketch=1.67MB)
    - firmware-ci.yml: add --output-dir to both compile steps
    - firmware-ci.yml: upload .bin/.elf as workflow artifacts on every CI run
    - release.yml: new workflow triggered by v*.*.* tags
    compiles both sketches, creates GitHub Release, attaches flashable .bin files
    includes esptool.py flashing instructions in release notes body
    - gui/robot_controller_ui.py: run ruff format to fix CRLF->LF line endings
    resolves python-lint CI failure (ruff formatter check exit code 1)
    -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
    [robot_controller_ui.py]
2026-04-18 release: add v1.0.0 release workflow with full release notes and badge
    - release.yml: rewrite release body with comprehensive inline documentation
    includes asset table, esptool flashing commands with correct offsets,
    Arduino IDE alternative steps, first-time MAC/angle config instructions,
    Python dashboard setup, full hardware BOM, and docs links
    - README.md: add GitHub Releases badge linked to releases page
2026-05-08 Introduce encoders
    - Implemented initial MT6816 encoder feedback integration
    - Refactored stepper control for closed-loop odometry
    - Updated PID and config structures for encoders
    - Updated Python UI to reflect real-time encoder telemetry
2026-05-08 chore: fix codebase
    > remove ai SLOP
    > Add markdown document with 100+ what and hows (errors and how to fix)
    >miscellaneous changes
    [BaseLink.ino, Controller.ino, config.h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]
2026-05-10 fix(baselink.ino): core telemetry for the SerialBT buffer
    > robot_controller_ui.py: update default pid values
    > config.h: update comments
    [BaseLink.ino, config.h, robot_controller_ui.py]
2026-05-10 Refactor stability logic and clean up telemetry GUI
    [BaseLink.ino, config.h, robot_controller_ui.py]
2026-05-11 feat: LED feedback deadband and GUI stability improvements
    - Added LED_MOTION_DEADBAND to prevent flicker in minor balance adjustments\n- Smoothed LED intensity mapping transition\n- Fixed ModernRobotController missing 'pressed_keys' initialization\n- Resolved Python linting and formatting issues in GUI script\n- Updated .gitignore to exclude local upload scripts
    [BaseLink.ino, config.h, robot_controller_ui.py]
2026-07-12 feat(gui): add interactive 3D robot viewer and UI polish; add CAD STEP model
    - gui: new Robot3DViewer (pure tk.Canvas software renderer) with orbit/zoom,
    live pitch/heading/wheel animation driven by telemetry
    - gui: reworked center layout (plot + 3D pane), degree grid lines on pitch
    plot, sidebar header with connection status indicator
    - models: simplified robot STEP model generated from viewer geometry
    - scripts: cadquery-based STEP generator (generate_step_model.py)
    [2pybot_simplified.step]
2026-07-12 feat(firmware): add EvoFox One S gamepad bridge (Bluepad32 -> ESP-NOW)
    - New EvoFoxController firmware: pairs with EvoFox One S over Bluetooth
    using Bluepad32 and forwards drive commands via ESP-NOW using the
    existing JoystickPacket format (robot firmware unchanged)
    - Left stick Y = lean, right stick X = steer, A toggles enable, B kills
    - Deadzone, cubic expo, and EMA smoothing; motors disabled on link loss
    - Tunables split into config.h
2026-07-12 feat(cad): add NEMA17-style stepper motors to STEP model
    - Two stepper motor bodies (42.3 mm square, 40 mm long) on the axle
    line with pilot boss and 5 mm shafts extending to the wheel hubs
    - Regenerated models/2pybot_simplified.step
    [2pybot_simplified.step]
2026-07-12 feat(cad): add detailing to STEP model from concept render
    - Treaded tires (notched tread blocks), rim groove and hub spoke holes
    - Side camera pods with lens barrels
    - Top console with tilted display panel
    - Front vent slots and recessed side panels
    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
    [2pybot_simplified.step]
2026-07-12 fix(firmware): use ESP32 core 2.x APIs for Bluepad32 board package
    - Send callback signature changed to (const uint8_t*, esp_now_send_status_t)
    - Drop esp_mac.h include; use WiFi.macAddress() for MAC printout
2026-08-20 Revamp! switch to LQR Control Method
2026-08-20 feat(fw): drop ESP-NOW, pair EVOFOX directly over Bluetooth, add WS2812 expression ring on GPIO15 - what: bt_gamepad.h replaces espnow_comm.h but exposes the same joyForward/joySteering/joyEnable/las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
    [BaseLink.ino, bt_gamepad.h, config.h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]
2026-08-27 feature(BaseLink): Shift to TMC2226 Drivers!
    Enable StealthChop2, CoolStep2, StallGuard4, to aid in better stall detection, noise reduction, and power efficient control.
    [BaseLink.ino, config.h, stepper_control.cpp]
2026-08-27 Update Documentation for final merge
    update the CI builder files to accomodate the needed bluepad32 board manager
2026-09-08 feat(firmware): add camera payload controls and harden motion I/O
    - Add rate-controlled pan/zoom and capped PWM torch controls, remapping gamepad inputs and serial commands so the payload works in every robot state.
    - Share motor enable to free a payload GPIO, make PCNT overflow reads race-safe, and expand diagnostics plus release formatting for reliable tuning and builds.
2026-09-30 Update LQR Gains & wheel dia
2026-09-30 feat(firmware): add runtime tuning, auto-calibration and terrain-aware control
    - BaseLink.ino: integrate runtime parameters, auto-tuning and terrain adaptation; use explicit gamepad arm events, remove V-command auto-arming and extend debug telemetry.
    - PROTOCOL.md: document parameter commands, NVS persistence, odometry streams and host control messages.
    - autotune.h: add non-blocking routines for wobble reduction, pitch trim, wheel-radius calibration and stall-speed measurement.
    - bt_gamepad.h: define stick calibration state, guard button edges on connection and read stick shaping, axis signs and repeat timing from runtime parameters.
    - config.h: add defaults for radial deadzone, steering sn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
    [BaseLink.ino, autotune.h, bt_gamepad.h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]
2026-09-30 feat(platform): add Radxa console, Android app and rev5 enclosure
    - .gitattributes: set launcher line endings and preserve STL meshes and wrapper archives as binary files.
    - .github/workflows/android.yml: build debug and unsigned release APKs with JDK 17 and Android SDK 34.
    - README.md: describe LQR/LQI control, current clients, imported packages and enclosure print status.
    - docs/BaseLink/100+_WHAT_AND_HOWS.md: replace obsolete references with 126 checks mapped to current code.
    - docs/BaseLink/Config_and_Tuning_Guide.md: document runtime parameters, NVS actions, control modes and auto-tune limits.
    - docs/BaseLink/PID_Theory_and_Math.md: document LQR/LQI equations, filtering, steering and sa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
    [base.scad, base.stl, dims.scad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]
2026-09-30 feat(ops): deploy Radxa handlers after committed Git updates
    - scripts/radxa/deploy.py: apply relevant commit changes with build checks, selective restarts, configuration backups and health validation.
    - scripts/radxa/systemd/2pybot-deploy.service: run one deployment check with a process lock and a bounded timeout.
    - scripts/radxa/systemd/2pybot-deploy.timer: check the local checkout every ten seconds without fetching or pulling.
    - tests/test_radxa_deploy.py: cover failed builds, failed health checks, dirty checkouts, Git locks, overlapping pulls and no-op updates.
    - .github/workflows/radxa-deploy.yml: run deployment tests on Python 3.9 and 3.12.
    - scripts/radxa/README.md: document update co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
2026-09-30 fix(ci): prepare SDK and publish versioned firmware outputs
    - .github/workflows/android.yml: install platform-tools without requesting the retired Android SDK tools package.
    - .github/workflows/release.yml: pin verified firmware libraries, tag output filenames, publish build metadata and checksums, and update release instructions.
2026-10-11 fix(android): restrict sensor rotation to three orientations v3.1.5
2026-10-19 feat(firmware): replace stepper drive with M0601 BLDC hubs
    Use independent RS485 links and position-derived wheel velocity. Fix current and RPM polarity at -1 and isolate v4 motor tuning from stepper NVS.
    Separate balance and turn current, smooth turn release and heading hold, and reduce the default yaw rate. Update motor tuning UI, build hardware identity, documentation and offline regression checks for v4.0.0.
2026-10-20 fix(control): preserve BLDC balance torque at speed saturation
    Remove the supply-model speed clamp, pass balance acceleration directly to current feed-forward, and prevent velocity correction from braking against recovery. Bound virtual actuator windup by the existing current budget instead of vehicle speed.
    Retune delayed velocity feedback, accept queued UART replies before timeout, preserve legacy hub telemetry, and add captured-state regression coverage. Default full-stick HIGH to 1 m/s with MAXSPD=0 uncapped in v4.0.1.
2026-10-20 fix(firmware): tolerate transient RS485 reply loss during balance
    Preserve confirmed mode across a missing transaction, keep the healthy UART running, and require a fresh mode query after resynchronisation. Retain fault and sustained link-loss disarming, with detailed trigger logging.
2026-10-20 fix(firmware): restore per-cycle RS485 frames and full-stick speed headroom (4.0.3)
    - Send one frame per motor every control cycle again (supplied BaseLinkHub
    behaviour). 4.0.1/4.0.2 gated drive frames on the previous reply and
    resynchronised for >=10 ms, freezing a wheel's torque ~25 ms per lost reply.
    Mode safety unchanged: every reply carries the mode byte.
    - Full stick = min(DRIVEV, SPDHEAD x free speed, MAXSPD); SPDHEAD default 0.70
    keeps the catch margin. Navigation obeys the same limit. PR,VDRIVE readback.
    - Log motor fault transitions. Control gains unchanged.
    - Update BLDC native tests; add transport/balance simulation and analysis doc.
    Not flashed or physically validated.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
2026-10-20 feat(deploy): switch managed hotspot to 2.4 GHz
2026-10-20 fix(leds): restore original animations and blend deployment spin
2026-10-20 fix(leds): restore original animations and disable Radxa control
    Restore the pre-deployment ring renderer from 823aa85. Retire ESP32 LED leases, stop host and firmware-worker indicator writes, and disable the LED daemon for firmware-owned rings, including legacy esp32 configurations. Keep deployment progress in the dashboard and add ownership regression coverage.
2026-10-21 feat(leds): add GPIO32 blue button status indicator
    Use active-high PWM on a dedicated LEDC timer for boot, ready, arming, balancing breath, operator stop, maintenance and error patterns. Keep animation running through blocking startup and calibration with an independent ESP timer. Latch fault indication until the next arm request. Document wiring and patterns; local tests skipped at the owner's request.
2026-10-21 fix(leds): preserve stepper animations with DMA ring output
    Keep every animation branch from the original pre-BLDC stepper renderer at a8427f0. Replace interrupt-refilled RMT transmission with complete I2S1 DMA frames to address per-pixel colour corruption reported on START. Reset and clear the ring before the original boot swirl, and skip busy transfers in the control loop. Local tests skipped at the owner's request; physical confirmation remains required.
2026-10-21 fix(payload): detach zoom servo two seconds after its last command
    Track zoom commands independently from yaw and periodic PWM refreshes. Detach the zoom pin after two seconds, hold it low and reattach automatically on the next zoom or centre command. Preserve yaw idle behaviour and its shared PWM timer. Local tests skipped as requested.
2026-10-21 feat(bot): add operator commands and automatic SSH environment
    Install a dedicated command venv with directory-independent bot commands for firmware builds/flashing, deployment, calibration, settings, diagnostics, logs and backups. Add checksummed backup and era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
2026-10-22 feat(control): add default velocity balancing with current-mode fallback
    Add DRVMODE=2 for direct motor-driver velocity balancing and keep DRVMODE=0 bench-only and DRVMODE=1 current balancing. Make mode 2 the compiled default while preserving saved/live selections. Require confirmed driver modes, reject active mode/sign changes, allocate RPM to balance before steering and bypass the current-loop virtual-state clamp. Add VSIGN and transmitted-RPM telemetry, document driver-owned current limiting and zero-RPM stop behaviour, and fix CLI parameter-save readback timing. Preserve pre-existing stash conflict alternatives under build/pre-velocity-conflicts.patch and resolve to the published unrestr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
2026-11-02 fix(control): return to current-only control for the 18V 5S bot
    Remove the velocity balancing/bench command path and experimental parameters, restoring the published current-control baseline while retaining the bot CLI/SSH environment, GPIO32 status LED, ring DMA output and zoom release. Configure the owner-reported 18V supply estimate and 2.6kg mass. Add targeted RAM profile migration and updater compatibility so old velocity snapshots cannot restore DRVMODE=2 or experiment gains; preserve trim and calibration, with explicit PS persistence. Keep CLI parameter readback improvements. Preserve local handoff/simulation scratch in a named stash. ESP32 firmware compilation and Python lint passed;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
2026-11-02 feat(release): add direct steering and persistent video in 4.1.1
    Apply the confirmed raw TRIM=-1.4 with an input-profile migration and stronger direct steering defaults, preserving camera pan shaping separately. Remove the predictive governor from production and archive its historical simulation fixture; retain balance/fault/current protections. Keep WebRTC playback in the ViewModel with renderer rebinding and requested-playback retry, and require a two-second held orientation pose. Display control pitch separately and allow precise parameter entry. Build signed release APKs using the stable project development key. ESP32 compilation and Python lint passed; Android build and signature verifi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
2026-11-02 fix(ci): pin Python compatibility checks to Ubuntu 24.04
    Keep the Radxa Python 3.9 matrix on a runner with published interpreter builds instead of the Ubuntu 26.04 ubuntu-latest rollout.
2026-11-03 fix(control): remove yaw spring-back and verify saves in 4.2.0
2026-11-03 fix(deploy): support return to stable BLDC with portable tuning
